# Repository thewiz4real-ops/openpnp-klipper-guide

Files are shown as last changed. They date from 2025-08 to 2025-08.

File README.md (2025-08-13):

# OpenPnP + Klipper on SKR Mini E3 V3 (Windows + WSL2)

**One repo. Clean steps. Commands clearly marked for Windows or Ubuntu/WSL.**  
This guide fixes common pitfalls and clarifies the *“Z shows −61”* non‑issue (camera focus vs. nozzle Z).

## Quick Start
1. **Bill of Materials:** See [10-bom.md](docs/10-bom.md)
2. **Flash/Host Setup:** See [20-skr-mini-wsl2.md](docs/20-skr-mini-wsl2.md)
3. **Before Starting OpenPnP (each boot):** See [30-before-starting-openpnp.md](docs/30-before-starting-openpnp.md).
4. **OpenPnP ↔ Klipper driver (TCP bridge):** See [40-openpnp-driver.md](docs/40-openpnp-driver.md)
5. **Head rotation via fake extruder (EM/E0):** See [50-rotation-extruder.md](docs/50-rotation-extruder.md)
6. **Lights (ESP32 or SKR fans):** See [60-lights.md](docs/60-lights.md)
7. **Troubleshooting (Step → Problem → Solution):** See [70-troubleshooting.md](docs/70-troubleshooting.md)

👉 Example configs live in [`configs/`](configs/).

## Contributing
Found something to fix? Please open an Issue or a Pull Request.  
See [CONTRIBUTING.md](CONTRIBUTING.md).

## License
- Docs: **CC BY 4.0**
- Code/Configs: **MIT**

*Generated: 2025-08-13 21:21*

---

## Project Notes

- **Attribution:** This machine is **inspired by the LumenPnP open‑source project (v4)**. Most **3D printables** and the **stopper PCB** come from the LumenPnP v4 project.
- **Do not overwrite your own `machine.xml`:** The example in `configs/machine.xml` is **guidance only**. **Do not** replace your working OpenPnP `machine.xml` with it; copy settings over selectively.
- **BOM:** The bill of materials is now in **[10-bom.md](docs/10-bom.md)**.
- **Where to put the ring‑light KiCad project:** place it under **`hardware/ringlight-24v-2x4-osram/`**. (See **hardware/README.md** for folder layout.)

*Notes updated: 2025-08-13 21:35*

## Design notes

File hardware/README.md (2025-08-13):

# Hardware folder

Use this folder to keep mechanical and PCB design files together.

## Subfolders
- `ringlight-24v-2x4-osram/` — **Put your 24 V ring light KiCad project here** (schematic, PCB, 3D, gerbers).
- `z-gantry-juki/` — Models/drawings for the JUKI-compatible Z gantry.

## Mechanical Parts & Printables
- `aluminum-bed` — 460×300 mm bed with 30 mm hole grid and 45 mm camera hole.
- [LumenPnP v4 printables](https://github.com/opulo-inc/lumenpnp) — used for most printed parts in this build.

> Reminder: **Don’t overwrite** your working OpenPnP `machine.xml` with the one in `configs/`. Use that file as **guidance** and copy only the bits you need.

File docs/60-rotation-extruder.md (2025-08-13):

# Step 6 — Head Rotation on EM/E0 as Fake Extruder (Klipper)

**Goal:** Drive the head rotation motor from the SKR Mini E3 V3 EM/E0 driver using Klipper’s `[extruder]` so we get TMC current control.

## 3.1 Clean out old attempts
Remove previous blocks like:
```
[manual_stepper head_rot]
[stepper_generic head_rot]
[tmc2209 head_rot]
# or old [extruder] attempts
```

## 3.2 Config (example)
```ini
# --- PnP head rotation on EM driver (fake extruder) ---
[extruder]
step_pin: PB3
dir_pin: PB4              # add "!" if direction is backwards
enable_pin: !PD1
microsteps: 16
rotation_distance: 360    # 1 unit = 1°
nozzle_diameter: 0.4
filament_diameter: 1.75
heater_pin: PA1
sensor_type: temperature_mcu
control: watermark
min_temp: 0
max_temp: 999
min_extrude_temp: 0
max_extrude_only_distance: 100000
max_extrude_only_velocity: 200

[tmc2209 extruder]
uart_pin: PC11
tx_pin:  PC10
uart_address: 3
run_current: 0.45
hold_current: 0.10
stealthchop_threshold: 999
```

## 3.3 Test
**Ubuntu (WSL) → Mainsail console:**
```
RESTART
SET_STEPPER_ENABLE STEPPER=extruder ENABLE=1
DUMP_TMC STEPPER=extruder   # IOIN ... enn=0 means enabled
M83
G92 E0
G1 E90 F600   ; +90°
G1 E-90 F600  ; back
```
If backwards → `dir_pin: !PB4` and `RESTART`.

## 3.4 Macros
```ini
[gcode_macro ROT]
# ROT D=90  (relative degrees)
gcode:
  {% set d = params.D|float %}
  M83
  G1 E{d} F600

[gcode_macro ROTABS]
# ROTABS A=0  (absolute angle)
variable_pos: 0
gcode:
  {% set tgt = params.A|float %}
  {% set delta = tgt - printer["gcode_macro ROTABS"].pos %}
  SET_GCODE_VARIABLE MACRO=ROTABS VARIABLE=pos VALUE={tgt}
  M83
  G1 E{delta} F600
```

---

### Problem → Solution
- **Problem:** Locked but won’t move  
  **Solution:** Wrong STEP/DIR pins or still in absolute E (send `M83` or `G92 E0`).

- **Problem:** Hot driver at idle  
  **Solution:** Lower `hold_current`, or disable after idle with an `idle_timeout` macro.

- **Problem:** “Move exceeds maximum extrusion”  
  **Solution:** Either (a) send rotation on a separate `G1 E...` line, or (b) relax `[extruder]` limits (we already set safe high limits above).

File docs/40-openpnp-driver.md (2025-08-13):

# Step 4 — OpenPnP ↔ Klipper via TCP (Windows ↔ Ubuntu/WSL)

**Goal:** Run OpenPnP on Windows, Klipper in Ubuntu/WSL, connected over TCP.

## 2.1 Start the bridge
**Ubuntu (WSL):**
```bash
# Resolve the Klipper endpoint (pty or UDS)
DEV=$(readlink -f /tmp/printer || readlink -f /tmp/klippy_uds)
echo "$DEV"

# Start the TCP bridge (leave running)
socat -d -d -T300 TCP-LISTEN:5000,bind=127.0.0.1,reuseaddr,fork,crnl \
                  OPEN:$DEV,raw,echo=0
```

**Windows PowerShell (test):**
```powershell
$client = New-Object Net.Sockets.TcpClient("127.0.0.1",5000)
$w = New-Object IO.StreamWriter($client.GetStream()); $w.AutoFlush=$true
$r = New-Object IO.StreamReader($client.GetStream())
$w.WriteLine("M105"); Start-Sleep -Milliseconds 200
$r.ReadToEnd(); $client.Close()
# Expect:
# // Klipper state: Ready
# ok T0:xx.x /0.0
```

## 2.2 Configure the OpenPnP Gcode Driver
- **Connection:** TCP, Host `127.0.0.1`, Port `5000`, LF line ending, Timeout 2000–60000 ms.
- **Connect sequence:**
```
G90
M83
```
- **Home command:** `G28` (or `OPNP_HOME` macro, see below)
- **Get position:** `M114`
- **Position regex:**  
`(?i)X:(?<X>-?\d+\.?\d*)\s+Y:(?<Y>-?\d+\.?\d*)\s+Z:(?<Z>-?\d+\.?\d*)\s+E:(?<E>-?\d+\.?\d*)`
- **Move template (works):**
```
G1 {X:X%.4f}{Y:Y%.4f}{Z:Z%.4f}{E:E%.4f}F{FeedRate:%.0f}
```
> Tip: Enable “using-letter-variables” in the driver options.

**Optional macro (Klipper):**
```ini
[gcode_macro OPNP_HOME]
gcode:
  G28
  G90
  G92 X0 Y0 Z0 E0
  M114
```

---

### Problem → Solution
- **Problem:** Timeouts on first connect  
  **Solution:** Add `M105` to the connect sequence and raise timeout. Confirm bridge with the PowerShell round‑trip test above.

- **Problem:** Driver sends raw `{x:X...}` text to Klipper  
  **Solution:** Use the exact template above and the “using‑letter‑variables” option.

- **Problem:** PR nags about firmware detection  
  **Solution:** It’s benign if `M115` returns a Klipper line; you can quiet the warning with a static detected‑firmware string in `machine.xml`.

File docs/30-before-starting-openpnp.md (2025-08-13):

# Step 3 (Boot) — Before Starting OpenPnP (Windows + Ubuntu/WSL)

**Purpose:** These commands are the *per‑boot* steps you run **every time** you start Windows **before** launching OpenPnP.
They are **not** part of the installation process.

---

## What you’ll do each time

1. **Open two consoles**  
   - One **Windows** (Command Prompt or PowerShell)  
   - One **Ubuntu (WSL)**

2. **Windows console — attach the SKR to WSL**  
   Replace `1-1` with the BUSID shown by `usbipd list` for your SKR Mini:
   ```powershell
   usbipd attach --busid 1-1 --wsl -a
   ```
   > Tip: If you haven’t installed it yet (one time only): `winget install dorssel.usbipd-win`

3. **Ubuntu (WSL) console — start the TCP bridge**  
   Resolve Klipper’s printer endpoint and start `socat`. Leave this window running.
   ```bash
   # Resolve the real endpoint Klipper created
   DEV=$(readlink -f /tmp/printer || readlink -f /tmp/klippy_uds)
   echo "$DEV"

   # Bridge Windows <-> WSL (OpenPnP will connect to TCP 127.0.0.1:5000)
   socat -d -d -T300 TCP-LISTEN:5000,bind=127.0.0.1,reuseaddr,fork,crnl \
                  OPEN:$DEV,raw,echo=0
   ```

4. **(Optional) Windows test — confirm round‑trip**  
   From **Windows PowerShell**, verify Klipper answers `ok`:
   ```powershell
   $client = New-Object Net.Sockets.TcpClient("127.0.0.1",5000)
   $w = New-Object IO.StreamWriter($client.GetStream()); $w.AutoFlush=$true
   $r = New-Object IO.StreamReader($client.GetStream())
   $w.WriteLine("M105"); Start-Sleep -Milliseconds 200
   $r.ReadToEnd(); $client.Close()
   ```

5. **Start OpenPnP** (Windows) and connect the G‑code driver to **Host: `127.0.0.1` / Port: `5000`**.

---

## Stop / restart
- To stop the bridge, close the WSL window running `socat` (or `pkill -f socat`).  
- If OpenPnP disconnects, just restart step 3 and reconnect the driver.

## Common pitfalls
- **`Connection refused`**: Klipper didn’t create `/tmp/printer` yet → wait a few seconds or restart the Klipper service.  
- **Timeouts on first command**: Add `M105` to the driver “connect” sequence and raise timeout.  
- **Wrong BUSID**: Run `usbipd list` in Windows to find the right `--busid` for the SKR.

*Last updated: 2025-08-13 22:20*

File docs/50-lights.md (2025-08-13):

# Step 5 — Lights (ESP32 serial **or** SKR fan headers)

Pick one approach.

## Option A — ESP32 over Serial (Windows COMx)
- **Windows (OpenPnP):** Add a Serial driver (e.g., COM4 @ 115200, keep‑alive).  
  **Actuators mapping:**
  - `LIGHT_Z` → `{True:z on}{False:z off}`
  - `LIGHT_FLAT` → `{True:f on}{False:f off}`
- **Tip:** Close Arduino Serial Monitor or any app that might hold the COM port.

### Problem → Solution
- **Problem:** “timeout waiting for response”  
  **Solution:** Ensure only OpenPnP holds the COM port; raise timeout to ~5000 ms; unplug/replug device if Windows power‑saves the port.

## Option B — SKR Fan Headers (24 V LED rings)
**Klipper (Ubuntu/WSL):**
```ini
[fan_generic light_flat]
pin: PC7           # FAN1
cycle_time: 0.0005

[fan_generic light_z]
pin: PB15          # FAN2
cycle_time: 0.0005
```
**OpenPnP Boolean actuators:**  
`SET_FAN_SPEED FAN=<name> SPEED={0..1}`

### Problem → Solution
- **Problem:** Visible PWM banding in camera  
  **Solution:** Use small `cycle_time` (~0.0005 ≈ ~2 kHz) and/or adjust exposure.

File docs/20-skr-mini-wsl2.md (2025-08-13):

# Step 2 — SKR Mini E3 V3 + Klipper on Windows (WSL2)

**Goal:** Flash Klipper to SKR Mini E3 V3.0 and run Klipper host in Ubuntu (WSL2) on Windows.

## Hardware & Requirements
- SKR Mini E3 V3.0 (MCU STM32G0B1)
- 24 V PSU, USB‑A→Micro‑B data cable
- Windows 10/11 with WSL2 (Ubuntu 24.04 suggested)
- `usbipd-win` for USB into WSL (optional)

## Safe Power Sequence (prevents USB/UART lockups)
1. Set **5 V jumper** to `INT`
2. Remove **SW_USB** jumper
3. Turn **VIN (24 V) ON first**
4. Then plug in **USB**

## A) Pass the board into WSL (optional)
**Windows PowerShell (Admin):**
```powershell
winget install dorssel.usbipd-win
usbipd list
usbipd bind   --busid 1-1
usbipd attach --busid 1-1 --wsl --auto-attach
```

## B) Prepare Ubuntu (WSL)
**Ubuntu (WSL):**
```bash
sudo apt update
sudo apt install -y git build-essential python3-venv nginx curl unzip socat
```

## C) Build & Flash Klipper Firmware
**Ubuntu (WSL):**
```bash
git clone https://github.com/Klipper3d/klipper
cd klipper
make menuconfig
# MCU: STMicroelectronics STM32
# Processor: STM32G0B1
# Bootloader offset: 8KiB bootloader
# Interface: USB (PA11/PA12)
make
```
**Flash via SD (recommended):**
1. Copy `out/klipper.bin` to SD, rename to `firmware.bin`
2. Insert in SKR, power cycle
3. Green LED blinks while flashing; file becomes `FIRMWARE.CUR`

## D) Install Klipper & Moonraker services
**Ubuntu (WSL):**
```bash
# Klipper host
python3 -m venv ~/klippy-env
~/klippy-env/bin/pip install -r klipper/scripts/klippy-requirements.txt
sudo cp klipper/scripts/klipper.service /etc/systemd/system/
sudo sed -i "s;/home/pi;/home/$USER;g" /etc/systemd/system/klipper.service
sudo systemctl enable --now klipper

# Moonraker
git clone https://github.com/Arksine/moonraker ~/moonraker
python3 -m venv ~/moon-env
~/moon-env/bin/pip install -r ~/moonraker/scripts/requirements.txt
sudo cp ~/moonraker/scripts/moonraker.service /etc/systemd/system/
sudo sed -i "s;/home/pi;/home/$USER;g" /etc/systemd/system/moonraker.service
sudo systemctl enable --now moonraker
```

## E) Mainsail (UI) via nginx
**Ubuntu (WSL):**
```bash
mkdir -p ~/mainsail
curl -L https://github.com/mainsail-crew/mainsail/releases/latest/download/mainsail.zip -o mainsail.zip
unzip mainsail.zip -d ~/mainsail
sudo mkdir -p /var/www && sudo cp -r ~/mainsail /var/www/

sudo tee /etc/nginx/sites-available/mainsail >/dev/null <<'EOF'
server {
    listen 80 default_server;
    server_name _;
    root /var/www/mainsail;
    index index.html;
    location / { try_files $uri $uri/ @moonraker; }
    location @moonraker {
        proxy_pass http://127.0.0.1:7125;
        proxy_http_version 1.1;
        proxy_set_header Upgrade $http_upgrade;
        proxy_set_header Connection "upgrade";
        proxy_set_header Host $host;
    }
}
EOF
sudo ln -sf /etc/nginx/sites-available/mainsail /etc/nginx/sites-enabled/
sudo rm -f /etc/nginx/sites-enabled/default
sudo nginx -t && sudo systemctl restart nginx
```

## F) Find your MCU path
**Ubuntu (WSL):**
```bash
ls -l /dev/serial/by-id/
# copy usb-Klipper_stm32g0b1xx_...-if00
```

## G) Minimal `printer.cfg` (motion only)
See [`configs/printer.cfg`](../configs/printer.cfg).

---

### Problem → Solution
- **Problem:** 404 at `http://localhost/`  
  **Solution:** Ensure nginx site enabled & Moonraker running; re-run the nginx block above.

- **Problem:** MCU not found  
  **Solution:** Use `/dev/serial/by-id/...` path and confirm with `ls -l`. Ensure power sequence.

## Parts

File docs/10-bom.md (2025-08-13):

# Step 1 — Bill of Materials (BOM)

**This build is inspired by the LumenPnP v4 project.** Most 3D printables and the stopper PCB originate from LumenPnP v4.

> ⚠️ **Do not replace your OpenPnP `machine.xml` with the one in this repo.** Use `configs/machine.xml` as **guidance only** and copy settings over selectively.

---

## From AliExpress
- 1× 370 Mini Air Pump 3V–24V 2.4W 3 L/min Electric Micro Vacuum Booster Motor
- 1× SMT head motor NEMA8/NEMA11 with nozzle & air connector (JUKI500 kit, KSH04‑M5)
- 1× OpenPnP USB Interface 1.0MP 720p USB camera module (IR‑cut switch, 8 mm lens)
- 1× OpenPnP USB Interface 1.0MP 720p USB camera module (IR‑cut switch, 120° lens)
- 4× GT2 idler timing pulley 20T W6 B5
- 1× BIGTREETECH **SKR Mini E3 V3.0** (TMC2209 UART)
- 5 m × GT2 timing belt, 6 mm width
- 5 m × 3 mm ID × 5 mm OD clear hose (food grade) — for vacuum
- 1× 24 V small normally‑closed solenoid valve

## From Temu
- 4× NEMA17 stepper, ~1.0 A
- 2× 50‑pack T‑nuts **M3**
- 1× 50‑pack T‑nuts **M5**
- 1× Panel holders for 2020/3030/4040 (Euro standard T‑slot)
- 2× Nylon drag chain/towline (10×20 mm class)
- 1× 100‑pack M3‑0.5 ISO7380 button‑head (304 A2‑70)
- 1× 50‑pack slide‑in T‑nuts **M5** (20‑series)
- 1× 2020 connector set (20 corner brackets + 40 M5×8 + 40 M5 T‑nuts)
- 2× Dual Z‑axis stepper motor cables (≈1.5 m) for Ender‑3/CR‑10
- 1× XYZ stepper & endstop cable set (Ender‑3 class)
- 3× **MGN9H** linear rails 350 mm
- 2× **MGN9H** linear rails 100 mm
- 1× GT2 kit (8× 5 mm‑bore 20T pulleys + 5 m belt, 6 mm width)
- 1× Ten‑pack KSV2Z Anodized Black 2020 T‑slot profiles (~1000.8 mm each)

## Frame Cuts (from 2020 stock)
- X axis: **3 × 460 mm**
- Y axis: **4 × 420 mm**
- Bed extra reinforcement: **1 × 420 mm**

## Printables & PCBs (LumenPnP v4)
- **All 3D printed parts:** from **LumenPnP v4**.
- **Stopper PCB:** from **LumenPnP v4** as well.

## Other Plates & Modules
- **Aluminum bed:** **460 mm × 300 mm**, hole array every **30 mm**, rows offset (“staggered”), camera hole φ **45 mm**.
- **Z gantry** compatible with **JUKI nozzle** (folder provided under `hardware/`).
- **24 V ring light** — KiCad project goes under `hardware/ringlight-24v-2x4-osram/`.

## TODO / Community Help
- 4× **M2.5** screws for JUKI nozzle motor (lengths vary)
- Assorted **M3/M4/M5** screws — see assembly video for exact lengths
- If you can refine sizes, please submit a PR to update this BOM.

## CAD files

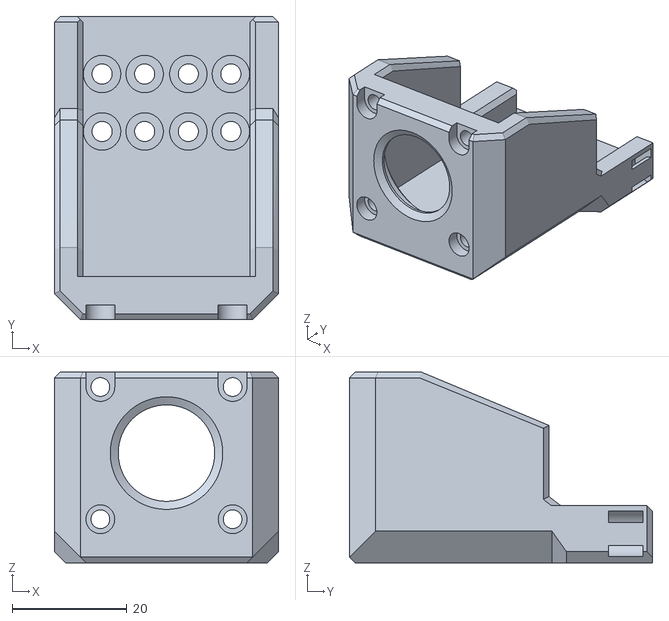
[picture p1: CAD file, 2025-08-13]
hardware/z-gantry-juki/z-gantry.obj
39.0 x 52.7 x 33.2

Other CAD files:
hardware/z-gantry-juki/z-gantry.blend

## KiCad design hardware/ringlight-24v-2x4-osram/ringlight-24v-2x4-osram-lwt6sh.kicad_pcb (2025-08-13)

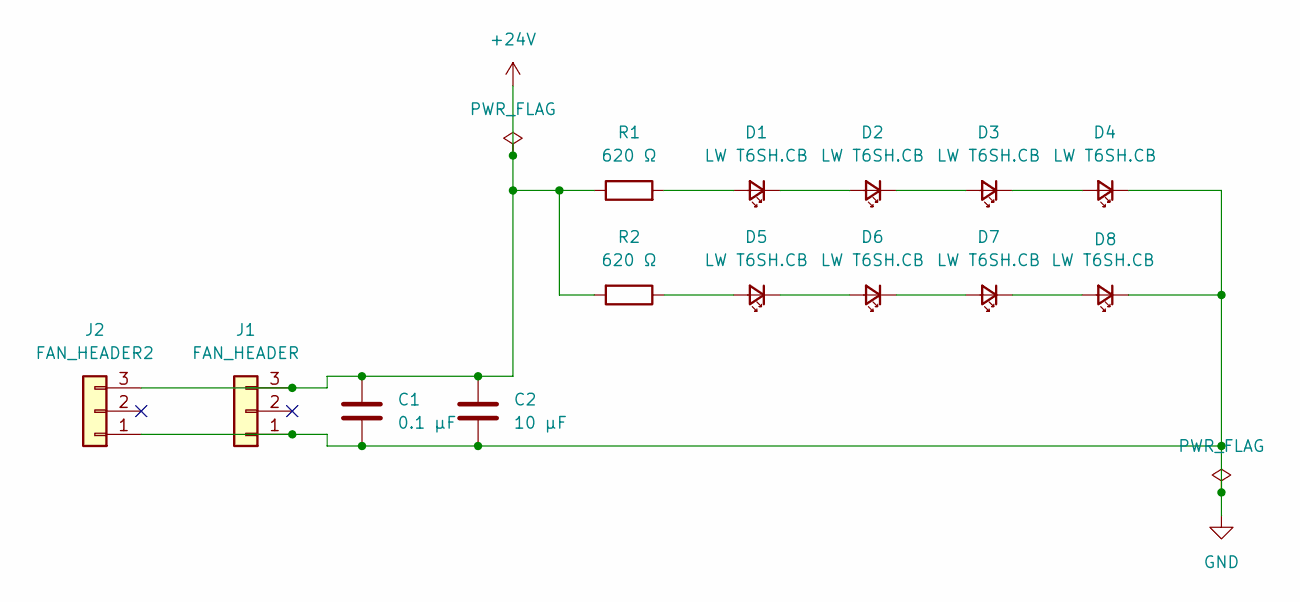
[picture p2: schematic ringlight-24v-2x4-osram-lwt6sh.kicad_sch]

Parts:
C1: 0.1 µF; C_0805_2012Metric
C2: 10 µF; C_0805_2012Metric
D1, D2, D3, D4, D5, D6, D7, D8: LW T6SH.CB; LED_PLCC_2835
J1: FAN_HEADER; JST_XH_B3B-XH-A_1x03_P2.50mm_Vertical
J2: FAN_HEADER2; JST_XA_S03B-XASK-1N-BN_1x03_P2.50mm_Horizontal
R1, R2: 620 Ω; R_1210_3225Metric

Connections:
+24V: C1.1, C2.1, J1.3, J2.3, R1.1, R2.2
GND: C1.2, C2.2, D4.1 (K), D8.1 (K), J1.1, J2.1
unnamed: D1.2 (A), R1.2
unnamed: D1.1 (K), D2.2 (A)
unnamed: D2.1 (K), D3.2 (A)
unnamed: D3.1 (K), D4.2 (A)
unnamed: D5.2 (A), R2.1
unnamed: D5.1 (K), D6.2 (A)
unnamed: D6.1 (K), D7.2 (A)
unnamed: D7.1 (K), D8.2 (A)

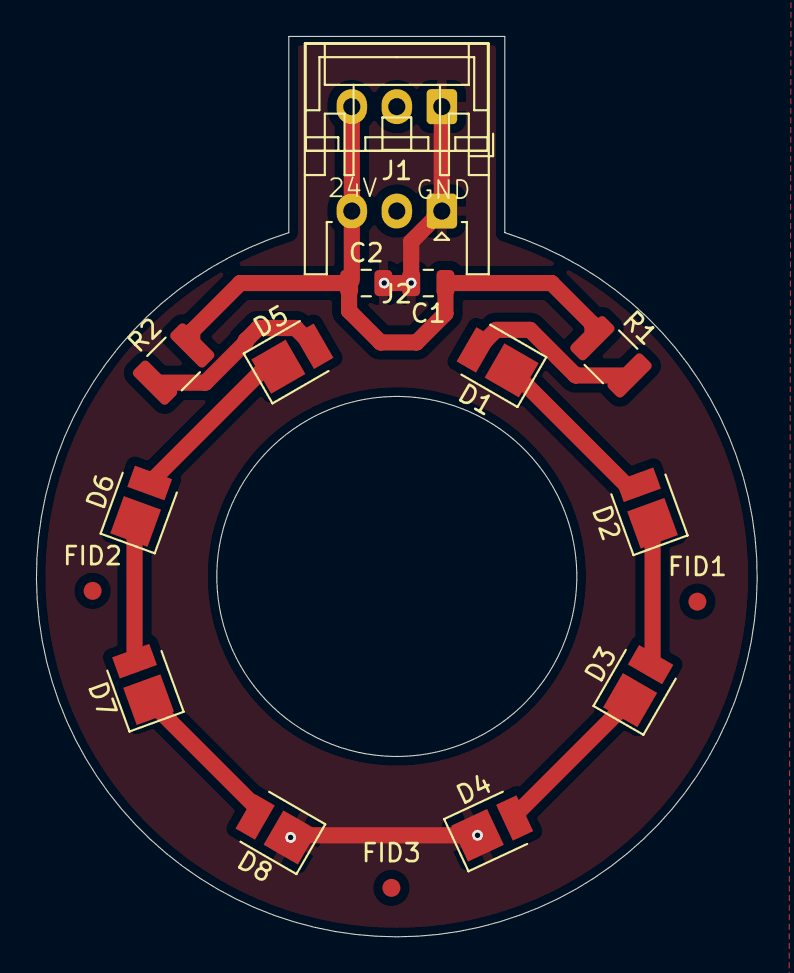
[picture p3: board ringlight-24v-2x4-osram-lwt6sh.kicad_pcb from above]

Board: 2 copper layers, 40.0 x 50.0 mm, 17 parts (0 on the bottom side), 10 nets.

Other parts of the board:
FID1, FID2, FID3: Fiducial_1mm_Mask2mm

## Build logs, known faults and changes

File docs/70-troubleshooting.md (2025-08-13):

# Step 7 — Troubleshooting (Step → Problem → Solution)

## A) Homing, Z travel, and the **“Z shows −61”** non‑issue
- **What you saw:** Z reads something like **−61** in OpenPnP.
- **Why it’s not a real problem:** That value is the **camera’s focus Z** from the **selected mountable** (TopCam/BottomCam), **not** the nozzle Z after homing.
- **Do this instead (steps):**
  1. Select **BottomCam** → center tray pocket → click **red crosshair** (captures **XY only**).
  2. Select **Head / Nozzle (H1/N1)** → lower nozzle to touch surface → click **blue “T”** next to Z (stores **nozzle Z** for that location).
  3. Set **Safe Z** in **Heads → H1** (e.g., 12–16 mm).
- **If Z moves out of range:** Match Klipper limits to real travel, e.g.:
  ```ini
  [stepper_z]
  position_endstop: 0.0
  position_max: 24
  max_z_velocity: 15
  max_z_accel: 100
  ```

## B) OpenPnP ↔ Klipper connect / template
- **Problem:** First command times out  
  **Solution:** Add `M105` to connect sequence; increase timeout.

- **Problem:** `{X:X...}` literal text in Klipper logs  
  **Solution:** Use the exact G1 template and enable “using‑letter‑variables”.

- **Problem:** Firmware detection nag  
  **Solution:** Safe to ignore if `M115` replies. Optionally set a static detected string in `machine.xml` to silence the warning.

## C) Bridge & Cameras
- **Problem:** `Connection refused` to 127.0.0.1:5000  
  **Solution:** Start `socat` after verifying `DEV=$(readlink -f /tmp/printer || readlink -f /tmp/klippy_uds)` prints a real path.

- **Problem:** Camera 0 fps / black / mono  
  **Solution:** Plug cameras into separate root USB ports; select YUY2 640×480@30fps; ensure no other app uses them.

## D) Rotation & Extruder limits
- **Problem:** “Move exceeds maximum extrusion” from Klipper  
  **Solution:** Send rotation in a separate `G1 E...` line or use generous `[extruder]` limits as shown in Step 3.

## E) Actuators
- **Problem:** Vacuum/air timings inconsistent  
  **Solution:** Use macros (see `configs/macros/`) and sequence with small delays (`G4 P150`).

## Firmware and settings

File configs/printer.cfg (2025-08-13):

################################################################
#  BASIC STARTER CONFIG – SKR Mini E3 V3  + 350×350×100 printer #
#################################################################

[mcu]
serial: /dev/serial/by-id/usb-Klipper_stm32g0b1xx_22001E000350415339373620-if00
baud: 115200
restart_method: command

#################################################################
# Motion and Axis Limits                                        #
#################################################################

[printer]
kinematics: cartesian
max_velocity: 450          # travel speed ceiling (mm/s)
max_accel: 6000            # XY accel
max_accel_to_decel: 6000
square_corner_velocity: 8  # keeps corners snappy without ringing
max_z_velocity: 25
max_z_accel: 300

#################################################################
# Stepper Motors                                                #
#################################################################

[stepper_x]
step_pin: PB13
dir_pin: PB12
enable_pin: !PB14
microsteps: 16
rotation_distance: 40
endstop_pin: ^!PC0
position_endstop: 0
position_max: 300
homing_speed: 50

[tmc2209 stepper_x]
uart_pin: PC11
tx_pin:  PC10
uart_address: 0
run_current: 0.90
stealthchop_threshold: 0

[stepper_y]
step_pin: PB10
dir_pin: !PB2
enable_pin: !PB11
microsteps: 16
rotation_distance: 40
endstop_pin: ^!PC1
position_endstop: 0
position_max: 350
homing_speed: 50

[tmc2209 stepper_y]
uart_pin: PC11
tx_pin:  PC10
uart_address: 1
run_current: 0.90
stealthchop_threshold: 0

[stepper_z]
step_pin: PB0
dir_pin: !PC5
enable_pin: !PB1
microsteps: 16
rotation_distance: 12
endstop_pin: ^!PC2
position_endstop: 0.0
position_max: 18.7
homing_speed: 4
homing_positive_dir: false


[tmc2209 stepper_z]
uart_pin: PC11
tx_pin:  PC10
uart_address: 2
run_current: 0.90
stealthchop_threshold: 0

#[manual_stepper head_rot]
#step_pin: PB3
#dir_pin: PB4          # change to !PB4 if direction is wrong
#enable_pin: !PD1      # flip to PC3 if it never enables
#microsteps: 16
#rotation_distance: 360
#velocity: 10
#accel: 100

[extruder]
step_pin: PB3
dir_pin: PB4            # add ! if backwards
enable_pin: !PD1        # PD1 low = enabled (you proved PD1 is the one)
microsteps: 16
rotation_distance: 360  # 1 unit = 1°
nozzle_diameter: 0.4    # dummy
filament_diameter: 1.75 # dummy
heater_pin: PA1
sensor_type: temperature_mcu
control: watermark
min_temp: 0
max_temp: 999
min_extrude_temp: 0
max_extrude_only_distance: 100000
max_extrude_only_velocity: 200

[tmc2209 extruder]
uart_pin: PC11
tx_pin:  PC10
uart_address: 3
run_current: 0.45       # LOWER THIS! try 0.40–0.55
hold_current: 0.10      # low hold current so it doesn't cook while idle
stealthchop_threshold: 999

#################################################################
# Extruder                                                      #
#################################################################

[extruder]
min_extrude_temp: 0
max_extrude_cross_section: 100000
max_extrude_only_distance: 100000

#[extruder]
#step_pin: PB3
#dir_pin: PB2
#enable_pin: !PC3
#microsteps: 16
#rotation_distance: 34.924
#nozzle_diameter: 0.400
#filament_diameter: 1.750
#heater_pin: PA1
#sensor_type: EPCOS 100K B57560G104F
#sensor_pin: PA0
#control: pid
#pid_Kp: 22.2
#pid_Ki: 1.08
#pid_Kd: 114
#min_temp: 10
#max_temp: 275
#min_extrude_temp: 170

#################################################################
# Bed Heater                                                    #
#################################################################

#[heater_bed]
#heater_pin: PA3
#sensor_type: EPCOS 100K B57560G104F
#sensor_pin: PA2
#control: pid
#pid_Kp: 63.0
#pid_Ki: 2.25
#pid_Kd: 440.0
#min_temp: 0
#max_temp: 130

#################################################################
# Fans                                                          #
#################################################################

[fan]
pin: PA4

#[heater_fan hotend_fan]
#heater: extruder
#pin: PC5

[fan_generic controller_fan]
pin: PA7
max_power: 1.0        # full speed at S255
shutdown_speed: 0     # off when Klipper shuts down

# FAN1 (PC7) -> "flat" / bottom light
[fan_generic light_flat]
pin: PC7
max_power: 1.0
kick_start_time: 0.0
off_below: 0.0
cycle_time: 0.001        # 1 kHz PWM; raise to 0.0005 (2 kHz) if needed

# FAN2 (PB15) -> "Z" / nozzle light
[fan_generic light_z]
pin: PB15
max_power: 1.0
kick_start_time: 0.0
off_below: 0.0
cycle_time: 0.001

[gcode_macro F_ON]
gcode: SET_FAN_SPEED FAN=light_flat SPEED=1.0

[gcode_macro F_OFF]
gcode: SET_FAN_SPEED FAN=light_flat SPEED=0.0

[gcode_macro Z_ON]
gcode: SET_FAN_SPEED FAN=light_z SPEED=1.0

[gcode_macro Z_OFF]
gcode: SET_FAN_SPEED FAN=light_z SPEED=0.0

# Optional: set brightness 0..255 like an LED
[gcode_macro F_SET]
gcode:
  {% set s = params.S|default(255)|int %}
  SET_FAN_SPEED FAN=light_flat SPEED={(s/255.0)}

[gcode_macro Z_SET]
gcode:
  {% set s = params.S|default(255)|int %}
  SET_FAN_SPEED FAN=light_z SPEED={(s/255.0)}

#################################################################
# Display (12864)                                               #
#################################################################

#[display]
#lcd_type: st7920
#cs_pin: PA15
#sclk_pin: PB10
#sid_pin: PB12
#encoder_pins: ^PC6, ^PC7
#click_pin: ^!PB13

[output_pin PUMP]
pin: PC9 # HB MOSFET
pwm: false
value: 0
shutdown_value: 0

[output_pin SOL]
pin: PC8 # E0 MOSFET
pwm: false
value: 0
shutdown_value: 0

[virtual_sdcard]
path: ~/printer_data/gcodes


#################################################################
# G-Code Macros                                                 #
#################################################################

[gcode_macro START_PRINT]
gcode:
    G28
    G90
    M117 Printing…

[gcode_macro END_PRINT]
gcode:
    M104 S0
    M140 S0
    G91
    G1 Z+5 F300
    G90
    M84
[gcode_macro M6]
gcode:
    M117 Tool change ignored


[gcode_macro VAC_ON]
gcode:
  SET_PIN PIN=PUMP VALUE=1
  M400

[gcode_macro VAC_OFF]
gcode:
  SET_PIN PIN=PUMP VALUE=0
  M400

[gcode_macro AIR_ON]
gcode:
  SET_PIN PIN=SOL VALUE=1
  M400

[gcode_macro AIR_OFF]
gcode:
  SET_PIN PIN=SOL VALUE=0
  M400

# Optional: ensure you never blow while vacuum is on
[gcode_macro VAC_PICK]
gcode:
  AIR_OFF
  SET_PIN PIN=PUMP VALUE=1

[gcode_macro VAC_RELEASE]
gcode:
  SET_PIN PIN=PUMP VALUE=0
  G4 P100            ; 100 ms settle
  AIR_ON
  G4 P150            ; short puff
  AIR_OFF

#[gcode_macro CHECK_ENN]
#gcode:
#  DUMP_TMC STEPPER=extruder

[idle_timeout]
timeout: 30
gcode:
  SET_STEPPER_ENABLE STEPPER=extruder ENABLE=0

[gcode_macro OPNP_HOME]
description: Home for OpenPnP and zero coordinates
gcode:
  G28
  G90
  G92 x0 y0 z0 e0
  M114

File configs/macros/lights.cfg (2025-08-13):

# Lights via SKR fans
[gcode_macro LIGHT_FLAT_ON]
gcode: SET_FAN_SPEED FAN=light_flat SPEED=1.0

[gcode_macro LIGHT_FLAT_OFF]
gcode: SET_FAN_SPEED FAN=light_flat SPEED=0

[gcode_macro LIGHT_Z_ON]
gcode: SET_FAN_SPEED FAN=light_z SPEED=1.0

[gcode_macro LIGHT_Z_OFF]
gcode: SET_FAN_SPEED FAN=light_z SPEED=0

# Vacuum / Air example
[gcode_macro VAC_ON]
gcode: SET_FAN_SPEED FAN=vacuum SPEED=1.0

[gcode_macro VAC_OFF]
gcode: SET_FAN_SPEED FAN=vacuum SPEED=0

[gcode_macro AIR_ON]
gcode: SET_FAN_SPEED FAN=air SPEED=1.0

[gcode_macro AIR_OFF]
gcode: SET_FAN_SPEED FAN=air SPEED=0

[gcode_macro RELEASE]
gcode:
  VAC_OFF
  AIR_ON
  G4 P150
  AIR_OFF

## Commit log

2025-08-13 Initial commit: OpenPnP + Klipper guide, configs, BOM, and templates
    Added full guide for running OpenPnP with Klipper on SKR Mini E3 V3 (Windows/WSL2).
    Includes:
    - Step by step setup docs
    - Config files
    - Troubleshooting
    - Bill of Materials
    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
    [lights.cfg, printer.cfg, ringlight-24v-2x4-osram-lwt6sh.kicad_pcb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]
2025-08-13 Fix README Quick Start links and add BOM at top
2025-08-13 Add per boot startup commands guide before launching OpenPnP
    - Created new docs/25-before-starting-openpnp.md for commands to run each time Windows starts before launching OpenPnP.
    - Moved USB/IP attach and socat bridge instructions out of installation guide.
    - Updated Quick Start in README.md to include the new step after host setup.
2025-08-13 Update and rename 30-openpnp-driver.md to 40-openpnp-driver.md
2025-08-13 Update and rename 40-rotation-extruder.md to 50-rotation-extruder.md
2025-08-13 Update and rename 50-rotation-extruder.md to 60-rotation-extruder.md
